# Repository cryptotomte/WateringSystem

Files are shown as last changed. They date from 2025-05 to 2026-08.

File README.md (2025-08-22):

# WateringSystem v2.3 (Hardware-Managed LDO Architecture)






## Overview
Cost-effective automated plant watering system with **2-domain optical isolation** for practical greenhouse automation. Features ESP32-based control, RS485 Modbus soil sensors, and simplified safety design optimized for enclosed environments.

**🔥 Latest Update v2.3**: Upgraded to TXS0108E bidirectional level shifter for faster RS485 communication - 1800x faster signal propagation while maintaining cost-effectiveness and reliability.

## Table of Contents
- [Features](#features)
- [Hardware Requirements](#hardware-requirements)
- [Software Dependencies](#software-dependencies)
- [Installation](#installation)
- [Usage](#usage)
- [Documentation](#documentation)
- [Testing](#testing)
- [Safety](#safety)
- [Contributing](#contributing)
- [License](#license)

## 🌟 Key Features

### Practical Safety & Isolation
- **Fast Level Shifting**: TXS0108E provides rapid voltage translation (110 Mbps)
- **2-Domain Architecture**: ESP32 (3.3V) → FIELD Domain (5V, level shifted)
- **Cost Effective**: Ultra-low cost design with high performance
- **Greenhouse Optimized**: Practical design for enclosed 12V environments

### Professional Monitoring
- **Multi-Parameter Soil Analysis**: NPK, pH, EC, moisture, temperature via RS485 Modbus
- **Environmental Sensing**: BME280 for ambient temperature, humidity, pressure
- **Real-time Monitoring**: Web interface with live sensor data
- **Remote Web Interface**: Responsive monitoring and configuration portal

### Smart Power Management
- **Hardware-Only Control**: LDO voltage converters provide always-on power management
- **Extended Runtime**: >48h operation on 20Ah LiFePO4 battery
- **Solar Ready**: MC4 connectors for future solar panel integration
- **Battery Monitoring**: Real-time voltage and capacity tracking
- **Simplified Design**: No software power control eliminates failure points
- **Instant Operation**: Always-on design eliminates startup delays

## 🔧 Hardware Architecture

### Hardware-Managed LDO System
```
12V LiFePO4 BATTERY ──┬── AMS1117-3.3 LDO ──► ESP32 Control Domain (Always-On)
                      │                      │ TXS0108E Level Shifter (3.3V↔5V)
                      │                      └── FIELD Domain (RS485 + Sensors)
                      │
                      └── AMS1117-5.0 LDO ──► Field Power Supply (Always-On)
                               │
                               └── Common Ground (GND_COMMON)
```

### Core Components
| Component | Model | Function | Domain |
|---|---|---|---|
| Microcontroller | ESP32-WROOM-32E | Main processor + WiFi | 3.3V Always-On |
| RS485 Interface | **SP3485EN** | Modbus communication | 5V Always-On |
| Level Shifter | **TXS0108E** | 3.3V↔5V voltage translation | Signal Path |
| Power Regulation | **AMS1117** | LDO voltage regulators | Hardware Control |
| Environmental | BME280 | Temperature/humidity | 3.3V Control |
| Soil Sensor | RS485 Modbus | NPK/pH/EC/moisture | 5V Field |

### ⚡ Hardware-Managed Safety Features
**LDO-based design provides reliable, always-on operation:**
- **Fast Level Shifting**: TXS0108E (110 Mbps capability with 10ns propagation)
- **Hardware Control**: LDO regulators eliminate software power management
- **Common Ground**: Simplified design prevents ground loop issues
- **Always-On**: Eliminates startup delays and power sequencing complexity
- **Maintenance Free**: No complex power domain monitoring required

## Software Dependencies
- **Framework**: Arduino framework for ESP32
- **Build System**: PlatformIO
- **Libraries**:
  - Wire (for I2C communication)
  - Adafruit BME280 (for environmental sensor)
  - ModbusMaster (for RS485 soil sensor)
  - ESPAsyncWebServer (for web interface)
  - AsyncElegantOTA (for OTA updates)
  - LittleFS (for file storage)
  - ArduinoJson (for data processing)

## Installation
1. Clone the repository:
```bash
git clone https://github.com/cryptotomte/WateringSystem.git
cd WateringSystem
```

2. Install PlatformIO (if not already installed):
```bash
pip install platformio
```

### Windows PowerShell Commands
On Windows systems, PlatformIO may not be in PATH. Use these commands:

```powershell
# Build project
& "C:\Users\crypt\.platformio\penv\Scripts\pio.exe" run --environment wateringsystem

# Upload to device  
& "C:\Users\crypt\.platformio\penv\Scripts\pio.exe" run --target upload --environment wateringsystem
```

3. Build and upload the firmware:
```bash
platformio run --target upload
```

4. Upload the file system (for web interface):
```bash
platformio run --target uploadfs
```

## Usage
1. **Initial Setup**
   - Power on the device
   - Connect to the WiFi network "WateringSystem-XXXX"
   - Navigate to 192.168.4.1 in your web browser
   - Follow the setup wizard to configure your home WiFi network

2. **Web Interface**
   - Access the web interface by navigating to the IP address of the device
   - Monitor current environmental and soil conditions
   - Configure watering schedules and thresholds
   - View historical data and system logs

3. **OTA Updates**
   - Access the update page at http://[device-ip]/update
   - Upload new firmware files through the web interface

## Documentation
Detailed documentation is available in the `docs` directory:
- [System Requirements Specification](docs/requirements.md)
- [Architecture Documentation](docs/architecture.md)
- [Hardware Documentation](docs/hardware.md)
- [User Guide](docs/user-guide.md)
- [Testing Documentation](docs/testing.md)
- [Safety Documentation](docs/safety.md)
- [Release Notes](docs/release-notes.md)

## Testing
The system includes unit tests and integration tests that can be executed using PlatformIO:

```bash
# Run all tests
platformio test

# Run specific test
platformio test -e test_sensors
```

For complete testing documentation, see [Testing Documentation](docs/testing.md).

## Safety
The WateringSystem interfaces with both water and electricity. Important safety considerations:
- All electrical components must be properly isolated from water
- Use waterproof enclosure for outdoor installations
- Include proper grounding for lightning protection in outdoor installations
- Power supply must be isolated and conform to safety standards

For complete safety information, see [Safety Documentation](docs/safety.md).

## Contributing
Contributions to the WateringSystem project are welcome! Please read [CONTRIBUTING.md](CONTRIBUTING.md) for details on our code of conduct and the process for submitting pull requests.

## License
This project is licensed under the GNU Affero General Public License v3.0 or later (AGPL-3.0-or-later) - see the [LICENSE](LICENSE) file for details.

**Key License Points:**
- ✅ Commercial use allowed
- ✅ Private use allowed  
- ✅ Modification allowed
- ⚠️ **Must share source code** when distributing binaries
- ⚠️ **Must share source code** when running as network service (SaaS)
- ⚠️ **Must preserve copyright** and license notices
- ⚠️ All modifications must use the same license

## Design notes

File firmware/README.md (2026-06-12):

# WateringSystem firmware (ESP-IDF)

ESP-IDF based firmware for the WateringSystem greenhouse controller
(ESP32-WROOM-32E, 4MB flash). This is the successor to the frozen
Arduino/PlatformIO firmware in the repository root.

- **ESP-IDF version:** v6.0.1 (pinned — in `Dockerfile` and CI)
- **Chip target:** `esp32`
- **Language:** C++ (IDF defaults, ~C++23 feature level)

## Building without a local toolchain (recommended)

No local ESP-IDF installation is needed. Always build with an **explicit
board selection**. From this `firmware/` directory:

```bash
# Rev 1 — ESP32 devkit + breakout (TXS0108E + SP3485)
docker run --rm -v "$PWD":/project -w /project espressif/idf:v6.0.1 \
  idf.py -DSDKCONFIG_DEFAULTS="sdkconfig.defaults;sdkconfig.board.rev1_devkit" build

# Rev 2 — custom PCB (THVD1426 auto-direction, INA226, CP2102N)
docker run --rm -v "$PWD":/project -w /project espressif/idf:v6.0.1 \
  idf.py -DSDKCONFIG_DEFAULTS="sdkconfig.defaults;sdkconfig.board.rev2" build
```

> **Warning:** omitting `SDKCONFIG_DEFAULTS` silently builds **rev1_devkit**
> (the Kconfig default), and the binaries are **identically named** for both
> boards. The two boards differ in safety-relevant ways (e.g. inverted level
> sensor polarity on rev2). Before flashing rev2 hardware, always verify the
> `Board:` line in the boot log matches the hardware.
>
> **Warning:** when switching boards, delete the generated `sdkconfig` (or
> run `idf.py fullclean`) first — overlays are only applied when `sdkconfig`
> is regenerated; otherwise the previous board's config is silently reused.

The first run pulls the image (~2 GB) and resolves managed components into
`managed_components/` (gitignored; `dependencies.lock` is tracked).

Pin mappings and board feature flags live in
`components/board/include/board/board.h` behind
`CONFIG_BOARD_REV1_DEVKIT` / `CONFIG_BOARD_REV2`.

## Host tests (no hardware needed)

The pump enforcement logic (timed runs, hard 300 s max-runtime cap, runtime
statistics) is pure C++ and is unit-tested natively on the ESP-IDF **linux
preview target** with the IDF-bundled Unity framework. From the repository:

```bash
cd firmware/test_apps/host
docker run --rm -v "$PWD":/project -w /project espressif/idf:v6.0.1 bash -c \
  "idf.py --preview set-target linux && idf.py build && ./build/pump_host_tests.elf"
echo $?   # 0 = all tests pass; >0 = number of failures
```

> **Note (macOS/OneDrive):** copy the tree to `/tmp` before mounting in
> Docker — the OneDrive path cannot be docker-mounted.

Coverage: max-runtime enforcement, duration self-stop, rejected starts
(0 s, > 300 s, already running), stop-when-stopped no-op, paired output
transitions and runtime statistics — all on a deterministic fake clock
(no sleeps). CI runs the same suite in the `host-test` job; the executable's
exit code equals the Unity failure count.

## Serial diagnostic console

The firmware starts an `esp_console` REPL on UART0 (same port as the logs,
115200 baud, prompt `ws>`) for bench-rig testing:

```
pump <plant|reservoir> start <seconds>   # timed run; 1..300
pump <plant|reservoir> stop
pump <plant|reservoir> status
pump status                              # both pumps
```

`help` lists all commands. Exact response formats are specified in
`specs/002-pump-gpio-board/contracts/serial-diagnostic.md`; the HIL
acceptance checklist is `specs/002-pump-gpio-board/checklists/hil.md`.

## Flash and monitor (initial bring-up only)

Routine updates will be delivered via OTA (phase 5). For initial bring-up,
flash over USB serial:

```bash
# With a local ESP-IDF installation:
idf.py -p /dev/ttyUSB0 flash monitor      # Linux
idf.py -p /dev/cu.usbserial-0001 flash monitor  # macOS

# Exit monitor with Ctrl-]
```

Docker on macOS cannot pass through USB serial devices; for bring-up either
use a Linux host (`docker run --device /dev/ttyUSB0 ...`) or flash the
CI-built binaries with esptool:

```bash
esptool.py --chip esp32 -p <PORT> write_flash \
  0x1000  build/bootloader/bootloader.bin \
  0x8000  build/partition_table/partition-table.bin \
  0x10000 build/wateringsystem.bin
```

## Partition layout (4MB)

| Name | Type | SubType  | Offset | Size | Purpose |
|---|---|---|---|---|---|
| nvs | data | nvs | 0x9000 | 0x4000 | Configuration storage |
| otadata  | data | ota | 0xd000 | 0x2000 | OTA slot selection |
| phy_init | data | phy | 0xf000 | 0x1000 | RF calibration data |
| ota_0 | app  | ota_0 | 0x10000  | 0x180000 | Application slot A |
| ota_1 | app  | ota_1 | 0x190000 | 0x180000 | Application slot B |
| storage  | data | littlefs | 0x310000 | 0xF0000  | Web assets, data logging |

A/B app slots with `CONFIG_BOOTLOADER_APP_ROLLBACK_ENABLE=y` provide
automatic rollback after a failed OTA boot (OTA itself arrives in phase 5).

## CI

`.github/workflows/firmware-build.yml` builds both board variants with
ESP-IDF v6.0.1 and uploads the binaries as artifacts. The push trigger is
**main-only**; feature branches build via PR or manual `workflow_dispatch`.

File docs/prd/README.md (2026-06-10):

# PRD breakdown — ESP-IDF migration

This directory breaks the master PRD ([`docs/PRD-esp-idf-migration.md`](../PRD-esp-idf-migration.md))
into PR-sized work packages for phases 1–6 of the Arduino → ESP-IDF firmware migration.

## How these files are used (spec-kit workflow)

Each `PR-NN-short-name.md` is a mini-PRD that seeds exactly one spec-kit feature run:

```
docs/prd/PR-NN-short-name.md
        │  speckit.specify / clarify / plan / tasks
        ▼
branch NNN-short-name  +  specs/NNN-short-name/ (spec.md, plan.md, tasks.md, checklists)
        │  implementation (subagents), checkpoints 1–3
        ▼
one reviewable PR to main (merge commit, never squash)
```

Rules (from the master PRD's working-method section):

- One PR-NN file → one feature branch → one PR. Each PR must merge with CI green.
- Implementer always delivers a test checklist: **CI**-tagged acceptance criteria are
  verified by GitHub Actions; **HIL**-tagged criteria become a checklist Paul runs on
  the bench rig (rev1 devkit + RS485 + soil sensor) at checkpoint 3.
- All commits, code, docs and issues in English (public repo).
- Order below keeps CI green at every merge point: no PR depends on unmerged work.

## Sync gates (parallel hardware track)

| Gate | Event | Gates |
|---|---|---|
| **SYNC 1** | rev2 pin map frozen (KiCad schematic done) | Final `BOARD_REV2` pin table in the board component (PR-02 ships rev1 table + provisional rev2 table; rev2 table is finalized at SYNC 1, at the latest before PR-14) |
| **SYNC 2** | rev2 boards delivered (JLCPCB) | All of phase 6 (PR-14) |

Phases 1–5 are developed and verified entirely on the rev1 devkit rig; the greenhouse
unit is never touched.

## Dependency graph

```
PR-01 phase0-foundation (done — this PR)
  │
  ├─► PR-02 pump-gpio-board ──◄ SYNC 1 (final rev2 pin table)
  │     ├─► PR-03 bme280-i2c
  │     ├─► PR-04 modbus-soil-sensor
  │     └─► PR-05 level-sensors-ina226
  │
  ├─► PR-06 nvs-littlefs-storage
  │     └─► PR-07 wifi-provisioning
  │           └─► PR-08 sntp-watchdog-logging
  │
  │   PR-06 + PR-07 ──► PR-09 http-server-api-v1 ──► PR-10 frontend-littlefs-assets
  │                          (live data: PR-03/04/05)
  │
  │   PR-02..05 + PR-06 + PR-08 ──► PR-11 watering-controller-host-tests
  │
  │   PR-09..11 ──► PR-12 parity-validation (HIL)
  │
  │   PR-06 + PR-09 ──► PR-13 ota-release
  │
  └────────────────► PR-14 rev2-bringup ◄── SYNC 2 (boards delivered)
                          (after PR-12 + PR-13)
```

## Work packages

| PR | Title | Phase | Depends on | Sync gates | Size | Status |
|---|---|---|---|---|---|---|
| PR-01 | [phase0-foundation](PR-01-phase0-foundation.md) | 0 | — | — | L | **done** (this PR) |
| PR-02 | [pump-gpio-board](PR-02-pump-gpio-board.md) | 1 | PR-01 | SYNC 1 (final rev2 table) | M | pending |
| PR-03 | [bme280-i2c](PR-03-bme280-i2c.md) | 1 | PR-02 | — | M | pending |
| PR-04 | [modbus-soil-sensor](PR-04-modbus-soil-sensor.md) | 1 | PR-02 | — | M | pending |
| PR-05 | [level-sensors-ina226](PR-05-level-sensors-ina226.md) | 1 | PR-02 | — | M | pending |
| PR-06 | [nvs-littlefs-storage](PR-06-nvs-littlefs-storage.md) | 2 | PR-01 | — | M | pending |
| PR-07 | [wifi-provisioning](PR-07-wifi-provisioning.md) | 2 | PR-06 | — | L | pending |
| PR-08 | [sntp-watchdog-logging](PR-08-sntp-watchdog-logging.md) | 2 | PR-06, PR-07 | — | M | pending |
| PR-09 | [http-server-api-v1](PR-09-http-server-api-v1.md) | 3 | PR-06, PR-07 (live data: PR-03/04/05) | — | L | pending |
| PR-10 | [frontend-littlefs-assets](PR-10-frontend-littlefs-assets.md) | 3 | PR-09 | — | M | pending |
| PR-11 | [watering-controller-host-tests](PR-11-watering-controller-host-tests.md) | 4 | PR-02..05, PR-06, PR-08 | — | L | pending |
| PR-12 | [parity-validation](PR-12-parity-validation.md) | 4 | PR-09, PR-10, PR-11 | — | M | pending |
| PR-13 | [ota-release](PR-13-ota-release.md) | 5 | PR-06, PR-09 | repo-publication decision | L | pending |
| PR-14 | [rev2-bringup](PR-14-rev2-bringup.md) | 6 | PR-05, PR-12, PR-13 | **SYNC 2** | L | pending |

## Notes on the split

- The breakdown follows the master PRD's phase definitions (Fasdefinitioner table)
  one-to-one; each phase's completion criterion is covered by the last PR of that phase.
- PR-02 carries the board component (pin maps, Kconfig feature flags) because the pump
  driver is the smallest driver and every other phase-1 PR consumes the board component.
- INA226 rides with the level sensors in PR-05 (both are small, rev2-relevant drivers;
  INA226 is driver + raw measurements only — protection features are an explicit
  non-goal, see master PRD "Ingår EJ").
- PR-12 (parity validation) is a thin PR by design: its deliverable is the ticked-off
  `docs/parity-checklist.md` plus gap fixes found on the rig — kept separate from PR-11
  so the host-tested controller port merges without waiting for rig time.

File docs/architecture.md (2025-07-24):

# WateringSystem Architecture

## Overview

This document describes the architectural design of the WateringSystem project. The architecture follows a modular, layered approach with clear separation of concerns and interface-based design principles.

## System Architecture

The WateringSystem follows a layered architecture pattern to ensure modularity, testability, and maintainability. The system is divided into the following layers:

```
┌─────────────────────────────────────────────┐
│               User Interface                │
│         (Web Server, HTML/CSS/JS)           │
└───────────────────────┬─────────────────────┘
                        │
┌───────────────────────▼─────────────────────┐
│             Application Logic                │
│      (Watering Rules, Scheduling, etc.)     │
└───────────────────────┬─────────────────────┘
                        │
┌───────────────────────▼─────────────────────┐
│           Service Layer                      │
│  (Sensor Data Processing, Data Storage)      │
└───────────────────────┬─────────────────────┘
                        │
┌───────────────────────▼─────────────────────┐
│        Hardware Abstraction Layer            │
│    (Sensor & Actuator Interface Classes)     │
└───────────────────────┬─────────────────────┘
                        │
┌───────────────────────▼─────────────────────┐
│             Hardware Drivers                 │
│     (BME280, RS485, Soil Sensor, Pump)      │
└─────────────────────────────────────────────┘
```

### Layers Description

1. **User Interface Layer**
   - Provides web-based interface for monitoring and control
   - Implements a lightweight web server
   - Serves HTML, CSS, and JavaScript content from LittleFS
   - Handles user authentication and authorization

2. **Application Logic Layer**
   - Implements watering rules and decision logic
   - Manages scheduling and timing of watering events
   - Handles alerts and notifications for out-of-range conditions
   - Processes user configuration changes

3. **Service Layer**
   - Processes raw sensor data into meaningful values
   - Manages data persistence (configuration, logs, history)
   - Implements Modbus RTU protocol for soil sensor communication
   - Provides data access services to upper layers

4. **Hardware Abstraction Layer**
   - Defines interfaces for all hardware components
   - Provides concrete implementations for each hardware device
   - Abstracts hardware details from upper layers
   - Enables mock implementations for testing

5. **Hardware Drivers Layer**
   - Implements low-level communication with hardware
   - Handles I2C, RS485, and GPIO communications
   - Manages power control and timing requirements
   - Reports hardware errors to upper layers

## Component Diagram

```
┌─────────────────────────────────────────────────────────────────┐
│                         WateringSystem                          │
└───────────────────────────────┬─────────────────────────────────┘
                                │
        ┌─────────────────────────────────────────────┐
        │                                             │
┌───────▼────────┐    ┌────────────────┐    ┌─────────▼─────────┐
│    WebServer   │    │ ConfigManager  │    │   SensorManager   │
└───────┬────────┘    └────────┬───────┘    └─────────┬─────────┘
        │                      │                      │
        │             ┌────────▼───────┐     ┌────────▼────────┐
        │             │ DataRepository │     │  SensorFactory  │
        │             └────────────────┘     └────────┬────────┘
        │                                             │
┌───────▼────────┐                           ┌────────▼────────┐
│   HTTPHandler  │                           │   ISensor       │◄────┐
└────────────────┘                           └────────┬────────┘     │
                                                      │              │
                          ┌─────────────────┬─────────┼──────────┐   │
                          │                 │         │          │   │
                 ┌────────▼───────┐ ┌───────▼────┐ ┌─▼────────┐ │   │
                 │ BME280Sensor   │ │ SoilSensor │ │ MockSensor│ │   │
                 └────────────────┘ └───────┬────┘ └───────────┘ │   │
                                            │                    │   │
                                    ┌───────▼────────┐           │   │
                                    │ ModbusClient   │           │   │
                                    └────────────────┘           │   │
                                                                 │   │
┌────────────────┐                                   ┌───────────▼─┐ │
│ WateringRules  │◄──────────────────────────────────┤ SensorReading│ │
└───────┬────────┘                                   └───────────┬─┘ │
        │                                                        │   │
┌───────▼────────┐                                               │   │
│ PumpController │◄──────────────────────────────────────────────┘   │
└───────┬────────┘                                                    │
        │                                                             │
┌───────▼────────┐     ┌────────────────┐                            │
│   IActuator    │◄────┤  MockActuator  │────────────────────────────┘
└───────┬────────┘     └────────────────┘
        │
┌───────▼────────┐
│    WaterPump   │
└────────────────┘
```

## Key Interfaces

The architecture is built around a set of key interfaces that enable modularity and testability:

### Sensor Interfaces

```cpp
/**
 * Base interface for all sensors
 */
class ISensor {
public:
    virtual ~ISensor() = default;
    
    /**
     * Initialize the sensor
     * @return true if initialization successful, false otherwise
     */
    virtual bool initialize() = 0;
    
    /**
     * Read sensor data
     * @return true if reading successful, false otherwise
     */
    virtual bool read() = 0;
    
    /**
     * Check if sensor is available and working
     * @return true if sensor is available, false otherwise
     */
    virtual bool isAvailable() = 0;
    
    /**
     * Get last error code
     * @return error code, 0 if no error
     */
    virtual int getLastError() = 0;
};

/**
 * Interface for environmental sensors
 */
class IEnvironmentalSensor : public ISensor {
public:
    /**
     * Get temperature in Celsius
     * @return temperature value
     */
    virtual float getTemperature() = 0;
    
    /**
     * Get relative humidity in percent
     * @return humidity value
     */
    virtual float getHumidity() = 0;
};

/**
 * Interface for soil sensors
 */
class ISoilSensor : public ISensor {
public:
    /**
     * Get soil moisture in percent
     * @return moisture value
     */
    virtual float getMoisture() = 0;
    
    /**
     * Get soil temperature in Celsius
     * @return temperature value
     */
    virtual float getTemperature() = 0;
    
    /**
     * Get soil pH level
     * @return pH value
     */
    virtual float getPH() = 0;
    
    /**
     * Get electrical conductivity in µS/cm
     * @return EC value
     */
    virtual float getEC() = 0;
    
    /**
     * Get nitrogen level
     * @return nitrogen value
     */
    virtual float getNitrogen() = 0;
    
    /**
     * Get phosphorus level
     * @return phosphorus value
     */
    virtual float getPhosphorus() = 0;
    
    /**
     * Get potassium level
     * @return potassium value
     */
    virtual float getPotassium() = 0;
};
```

### Actuator Interfaces

```cpp
/**
 * Base interface for all actuators
 */
class IActuator {
public:
    virtual ~IActuator() = default;
    
    /**
     * Initialize the actuator
     * @return true if initialization successful, false otherwise
     */
    virtual bool initialize() = 0;
    
    /**
     * Check if actuator is available and working
     * @return true if actuator is available, false otherwise
     */
    virtual bool isAvailable() = 0;
    
    /**
     * Get last error code
     * @return error code, 0 if no error
     */
    virtual int getLastError() = 0;
};

/**
 * Interface for water pump control
 */
class IWaterPump : public IActuator {
public:
    /**
     * Start the pump
     * @return true if operation successful, false otherwise
     */
    virtual bool start() = 0;
    
    /**
     * Stop the pump
     * @return true if operation successful, false otherwise
     */
    virtual bool stop() = 0;
    
    /**
     * Run the pump for a specific duration
     * @param seconds Duration to run in seconds
     * @return true if operation successful, false otherwise
     */
    virtual bool runFor(unsigned int seconds) = 0;
    
    /**
     * Check if the pump is currently running
     * @return true if running, false otherwise
     */
    virtual bool isRunning() = 0;
};
```

### Communication Interfaces

```cpp
/**
 * Interface for Modbus communication
 * 
 * Implementation Note (July 2025): SP3485ModbusClient provides production-ready
 * RS485 communication using TXS0108E level shifter with verified 50µs timing delays.
 * Supports full Modbus RTU protocol with error handling and automatic retry logic.
 */
class IModbusClient {
public:
    virtual ~IModbusClient() = default;
    
    /**
     * Initialize the Modbus client
     * @return true if initialization successful, false otherwise
     */
    virtual bool initialize() = 0;
    
    /**
     * Read holding registers from a Modbus device
     * @param deviceAddress Modbus device address
     * @param startRegister First register to read
     * @param count Number of registers to read
     * @param buffer Buffer to store read values
     * @return true if operation successful, false otherwise
     */
    virtual bool readHoldingRegisters(uint8_t deviceAddress, uint16_t startRegister, 
                                      uint16_t count, uint16_t* buffer) = 0;
    
    /**
     * Write single register to a Modbus device
     * @param deviceAddress Modbus device address
     * @param registerAddress Register address to write
     * @param value Value to write
     * @return true if operation successful, false otherwise
     */
    virtual bool writeSingleRegister(uint8_t deviceAddress, uint16_t registerAddress, 
                                    uint16_t value) = 0;
    
    /**
     * Get last error code
     * @return error code, 0 if no error
     */
    virtual int getLastError() = 0;
};
```

### Storage Interfaces

```cpp
/**
 * Interface for data storage
 */
class IDataStorage {
public:
    virtual ~IDataStorage() = default;
    
    /**
     * Initialize the storage
     * @return true if initialization successful, false otherwise
     */
    virtual bool initialize() = 0;
    
    /**
     * Store configuration data
     * @param key Configuration key
     * @param data Data to store
     * @return true if operation successful, false otherwise
     */
    virtual bool storeConfig(const String& key, const String& data) = 0;
    
    /**
     * Retrieve configuration data
     * @param key Configuration key
     * @param defaultValue Default value if key not found
     * @return Retrieved data or default value
     */
    virtual String getConfig(const String& key, const String& defaultValue = "") = 0;
    
    /**
     * Store sensor reading
     * @param sensorId ID of the sensor
     * @param readingType Type of reading (temperature, humidity, etc.)
     * @param value Reading value
     * @param timestamp Time of reading
     * @return true if operation successful, false otherwise
     */
    virtual bool storeSensorReading(const String& sensorId, const String& readingType, 
                                  float value, time_t timestamp) = 0;
    
    /**
     * Get sensor readings for a specific period
     * @param sensorId ID of the sensor
     * @param readingType Type of reading
     * @param startTime Start time of the period
     * @param endTime End time of the period
     * @return JSON string with readings
     */
    virtual String getSensorReadings(const String& sensorId, const String& readingType, 
                                   time_t startTime, time_t endTime) = 0;
};
```

## Data Flow

1. **Sensor Data Collection**
   - Sensors are read at configured intervals
   - Raw data is processed and converted to appropriate units
   - Processed data is stored in temporary storage
   - Readings are checked against configured thresholds

2. **Decision Making**
   - Soil moisture and other parameters are evaluated
   - If watering criteria are met, watering process is triggered
   - Historical data is considered for decision making
   - Scheduling rules are applied

3. **Actuation**
   - Water pump is activated for a calculated duration
   - Pump activity is monitored and logged
   - Safety checks are performed during operation

4. **User Interaction**
   - Web interface displays current status and historical data
   - User configures system parameters and schedules
   - System responds to manual commands
   - Alerts are displayed for out-of-range conditions

## Testing Approach

The architecture supports comprehensive testing at multiple levels:

1. **Unit Testing**
   - Each class is tested in isolation
   - Mock implementations of interfaces are used
   - Focus on individual component behavior

2. **Integration Testing**
   - Tests interaction between components
   - Verifies proper communication between layers
   - Focuses on interface compliance

3. **System Testing**
   - Tests the complete system behavior
   - Verifies end-to-end functionality
   - Simulates real-world scenarios

## Deployment

The system is deployed as firmware on the ESP32 microcontroller:

1. **Build Process**
   - PlatformIO builds the firmware
   - Web assets are processed and included in the binary
   - Configuration is embedded in the firmware

2. **Installation**
   - Firmware is flashed to the ESP32
   - Initial configuration is performed
   - System performs self-test and calibration

3. **Updates**
   - OTA (Over The Air) updates are supported
   - Configuration is preserved during updates
   - Version control ensures compatibility

## Future Extensions

The architecture is designed to support future extensions:

1. **Additional Sensors**
   - New sensor types can be added through interface implementation
   - Minimal impact on existing code

2. **Advanced Control Algorithms**
   - More sophisticated watering algorithms can be implemented
   - Machine learning integration for predictive watering

3. **External Integrations**
   - MQTT support for IoT integration
   - REST API for external system integration

4. **Mobile Application**
   - Companion mobile app could be developed
   - Would communicate with system via web API

## Hardware Architecture - LDO-Managed System

The WateringSystem implements a hardware-managed power architecture optimized for greenhouse automation applications. The system uses LDO voltage regulators with common ground and optical signal isolation, providing reliable operation without software power control complexity.

### Hardware-Managed Power Overview

The system uses an always-on LDO architecture with optical signal isolation:

```
┌─────────────────────────────────────────────────────────────────┐
│                 ESP32 Domain (3.3V LDO)                         │
│  ┌─────────────┐  ┌─────────────┐  ┌─────────────┐             │
│  │    ESP32    │  │   BME280    │  │  Status     │             │
│  │  DevKit v1  │  │   Sensor    │  │  LEDs       │             │
│  └─────────────┘  └─────────────┘  └─────────────┘             │
│                         │                                       │
│                         │ I2C (Direct connection)               │
│                         │                                       │
│  Reference: GND_COMMON                                          │
└───────────────────┬─────────────────────────────────────────────┘                    │ Level Shifting
                    │ (TXS0108E)
                    │ 3.3V ↔ 5V
┌───────────────────▼─────────────────────────────────────────────┐
│                 FIELD Domain (5V LDO Always-On)                 │
│  ┌─────────────────────────────────────────────────────────┐   │
│  │                SP3485EN IC                              │   │
│  │           RS485 Transceiver                             │   │
│  │          (Always powered)                               │   │
│  └─────────────────────────────────────────────────────────┘   │
│                                                                 │
│  ┌─────────────┐  ┌─────────────┐  ┌─────────────┐             │
│  │    Soil     │  │   Water     │  │  Reservoir  │             │
│  │   Sensors   │  │   Pumps     │  │   Sensors   │             │
│  │  (RS485)    │  │  (Relays)   │  │  (Digital)  │             │
│  └─────────────┘  └─────────────┘  └─────────────┘             │
│                                                                 │
│  Reference: GND_COMMON (Shared ground)                         │
└─────────────────────────────────────────────────────────────────┘
```

### Hardware Management Strategy

#### LDO Power Management: Always-On Design
- **Type**: AMS1117 LDO voltage regulators
- **ESP32 Domain**: 3.3V always-on power supply
- **Field Domain**: 5V always-on power supply
- **Ground**: Common ground plane (GND_COMMON)
- **Control**: Hardware-only, no software power management

#### TXS0108E Level Shifter: Fast Voltage Translation
- **Type**: 8-bit bidirectional voltage translator
- **Data Rate**: Up to 110 Mbps capability
- **Purpose**: Signal isolation between domains (signals only, not power)
- **Signals Isolated**: TX, RX, DE/RE control
- **Cost**: ~60 SEK total (3 units × 20 SEK)

### Hardware Benefits

1. **Simplicity**: No software power control eliminates complexity and failure modes
2. **Reliability**: Always-on design eliminates startup delays and power sequencing issues
3. **Stability**: LDO regulators provide excellent voltage regulation and low noise
4. **Cost Effectiveness**: Eliminates need for power control GPIO pins and monitoring circuits
5. **Common Ground**: Shared ground plane simplifies PCB design and eliminates ground loops

### Power Supply Architecture

```
12V Battery ──┬── AMS1117-3.3 LDO ──► ESP32 Domain (3.3V Always-On)
              │   (GND_COMMON)        Control logic, WiFi, BME280
              │
              └── AMS1117-5.0 LDO ──► FIELD Domain (5V Always-On)
                  (GND_COMMON)        RS485, sensors, pumps
```

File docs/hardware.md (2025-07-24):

# Hardware Specifications - WateringSystem v2.3 (Hardware-Managed LDO Architecture)

## Overview

This document provides complete hardware specifications for the hardware-managed WateringSystem designed for cost-effective greenhouse automation. The system uses LDO voltage converters with common ground and optical signal isolation - optimized for always-on 12V applications with hardware-only power management.

## Main Components

### 1. Microcontroller - ESP32-WROOM-32E

| Specification | Value |
|---|---|
| CPU | Dual-core Xtensa LX6 microprocessor |
| Clock Speed | Up to 240 MHz |
| Flash Memory | 4 MB |
| RAM | 520 KB SRAM |
| Wireless | Wi-Fi 802.11 b/g/n (2.4 GHz) + Bluetooth 4.2 |
| GPIO Pins | 34 programmable GPIO pins |
| ADC | 12-bit SAR ADC, up to 18 channels |
| Power Supply | 3.3V |
| Operating Temperature | -40°C to +85°C |

### 2. Environmental Sensor - BME280

| Specification | Value |
|---|---|
| Interface | I2C (Address: 0x76 or 0x77) |
| Temperature Range | -40°C to +85°C |
| Temperature Accuracy | ±0.5°C |
| Humidity Range | 0% to 100% RH |
| Humidity Accuracy | ±3% RH |
| Pressure Range | 300 to 1100 hPa |
| Pressure Accuracy | ±1 hPa |
| Supply Voltage | 1.71V to 3.6V |
| Current Consumption | 3.6 μA at 1 Hz |

### 3. Soil Sensor - RS485 Modbus Soil Sensor

| Specification | Value |
|---|---|
| Interface | RS485 Modbus RTU |
| Baud Rate | 9600 bps (default) |
| Data Format | 8N1 (8 data bits, no parity, 1 stop bit) |
| Device Address | Configurable (default: 0x01) |
| Moisture Range | 0% to 100% |
| Temperature Range | -40°C to +80°C |
| pH Range | 3 to 9 pH |
| EC Range | 0 to 20000 μS/cm |
| NPK Range | Nitrogen: 0-1999 mg/kg, Phosphorus: 0-1999 mg/kg, Potassium: 0-1999 mg/kg |
| Supply Voltage | 5V DC (LDO-managed always-on) |
| Current Consumption | < 50 mA (typical) |
| Cable Length | Up to 200 meters (adequate for greenhouse) |

**Modbus Register Map**

| Register | Description | Unit | Format |
|---|---|---|---|
| 0x0000 | Soil Moisture | % | Unsigned 16-bit |
| 0x0001 | Soil Temperature | 0.1°C | Signed 16-bit |
| 0x0002 | Soil pH | 0.1 pH | Unsigned 16-bit |
| 0x0003 | Soil EC | μS/cm | Unsigned 16-bit |
| 0x0004 | Nitrogen | mg/kg | Unsigned 16-bit |
| 0x0005 | Phosphorus | mg/kg | Unsigned 16-bit |
| 0x0006 | Potassium | mg/kg | Unsigned 16-bit |
| 0x0007 | Soil Humidity | % | Unsigned 16-bit |

### 4. RS485 Interface - MIKROE-4156 with Optical Isolation

**MikroElektronika RS485 5 Click (MIKROE-4156)**

| Specification | Value |
|---|---|
| Interface | UART to RS485 |
| Transceiver IC | ADM3485ARZ (Analog Devices) |
| Signal Rate | Up to 12 Mbps |
| Operating Voltage | 5V (LDO-managed) |
| ESD Protection | ±15kV on bus pins |
| Bus Load | Supports up to 32 transceivers |
| Interface | mikroBUS™ connector |
| Dimensions | 25.4 x 28.58 mm |

**TXS0108E Level Shifter (Voltage Translation)**

| Specification | Value |
|---|---|
| Type | 8-bit bidirectional voltage translator |
| Input Voltage (A-side) | 1.2V to 3.6V (ESP32: 3.3V) |
| Input Voltage (B-side) | 1.65V to 5.5V (RS485: 5.0V) |
| Data Rate | Up to 110 Mbps |
| Propagation Delay | 10ns typical |
| Package | 20-pin TSSOP |
| Operating Temperature | -40°C to +85°C |
| Channels Used | 3 (TX, RX, DE/RE) |
| **Verified Timing** | **50µs DE/RE switching delays (tested July 2025)** |
| **Communication Rate** | **9600 baud Modbus RTU verified functional** |

### 5. Water Pumps - 12V DC

| Specification | Value |
|---|---|
| Operating Voltage | 12V DC |
| Current | 0.5A - 1.5A (depending on pressure) |
| Flow Rate | 1-3 liters per minute |
| Maximum Head | 2-3 meters |
| Power Consumption | 6-18W |
| Duty Cycle | 30 minutes max continuous operation |
| Quantity | 2 pieces (plant pump + reservoir pump) |

### 6. Power Supply Components

**LiFePO4 Battery**

| Specification | Value |
|---|---|
| Voltage | 12V nominal |
| Capacity | 20Ah (240Wh) |
| Type | LiFePO4 (safe chemistry) |
| Operating Temperature | 0°C to 45°C |
| Cycle Life | >2000 cycles |

**LDO Voltage Converters (Always-On Hardware Management)**

| Component | Input | Output | Current | Efficiency | Type |
|---|---|---|---|---|---|
| AMS1117-3.3 (ESP32 domain) | 12V | 3.3V | 1A | >85% | LDO |
| AMS1117-5.0 (Field domain) | 12V | 5V | 1A | >85% | LDO |

**Key Features:**
- Hardware-only power management (no software control)
- Always-on operation with low dropout voltage
- Common ground design eliminates ground loop issues
- Thermal protection and current limiting
- Stable output voltage regulation

## Pin Assignments - Hardware-Managed LDO Architecture with TXS0108E

| GPIO | Connected To | Description |
| GPIO | Connected To | Description |
|------|--------------|-------------|
| GPIO 21 | I2C SDA | BME280 Data Line |
| GPIO 22 | I2C SCL | BME280 Clock Line |
| GPIO 17 | TX2 | RS485 TX (via TXS0108E A1) |
| GPIO 16 | RX2 | RS485 RX (via TXS0108E A2) |
| GPIO 25 | DE/RE | RS485 Direction Control (via TXS0108E A3) |
| GPIO 26 | Plant Pump Control | Main Water Pump MOSFET Gate |
| GPIO 27 | Reservoir Pump Control | Reservoir Filling Pump MOSFET Gate |
| GPIO 32 | Reservoir Low Level | Water Reservoir Low Level Sensor |
| GPIO 33 | Reservoir High Level | Water Reservoir High Level Sensor |
| GPIO 2 | Status LED | System Status Indicator |
| GPIO 5 | Button 1 | Manual Mode Button |
| GPIO 18 | Button 2 | Configuration Button |

**Pin Configuration Updates (July 2025):**
- **CRITICAL FIX:** GPIO 16/17 pin assignments corrected for proper RS485 communication
- Previous configuration had TX/RX pins swapped causing communication failures
- Now matches verified working test configuration: TX=GPIO17, RX=GPIO16
- TXS0108E timing delays optimized to 50µs for reliable level shifting
- All RS485 communication now fully functional with Modbus soil sensors

## Power Architecture - Hardware-Managed LDO System

### Power Domains

| Domain | Voltage | Ground | Control | Components |
|---|---|---|---|---|
| **ESP32** | 3.3V | GND_COMMON | LDO Always-On | ESP32, BME280, Control logic |
| **FIELD** | 5V | GND_COMMON | LDO Always-On | RS485 module, Soil sensor |

### Power Distribution

```
12V LiFePO4 Battery
├── LDO 3.3V → ESP32 Domain (control, WiFi, sensors)
└── LDO 5V   → Field Domain (RS485 + soil sensor)
     └── Common Ground (GND_COMMON) - No isolation required
```

### Hardware-Only Management Strategy

- **Always-On Design:** Both LDO converters provide continuous regulated power
- **No Software Control:** Power domains managed entirely by hardware
- **Common Ground:** Single ground plane simplifies design and eliminates ground loops
- **Level Shifting:** TXS0108E provides fast bidirectional voltage translation for RS485 signals
- **Safety Level:** Practical for enclosed 12V systems in ASA IP65 box

## Connection Diagram

```
                        ┌─────────────────┐
                        │                 │                        │      ESP32      │
                        │   (3.3V LDO)    │
                        └─┬───┬───┬───┬───┘
                          │   │   │   │
                          │   │   │   │
┌─────────────┐           │   │   │   │           ┌────────────┐
│             │◄──SDA─────┘   │   │   │           │ TXS0108E   │
│   BME280    │               │   │   │           │(3.3V↔5V)   │
│             │◄──SCL─────────┘   │   └───TX────►│ A1    B1 ──┼──►
└─────────────┘                   │               │ A2    B2 ──┼──◄─RX
                                  └───DE/RE─────►│ A3    B3 ──┼──►
                                                  │ OE←VCC     │
                                                  └──────┬─────┘
┌─────────────┐                                          │
│  Reservoir  │                                    ┌─────▼─────┐
│  Low Level  │◄──GPIO32───┐                       │           │
│   Sensor    │            │                       │  MIKROE   │
└─────────────┘            │                       │   4156    │
                           │                       │  (5V LDO  │
┌─────────────┐            │                       │Always-On) │
│  Reservoir  │            │                       └─────┬─────┘
│  High Level │◄──GPIO33───┤                             │
│   Sensor    │            │                        ┌────▼─────┐
└─────────────┘            │                        │          │
                           │                        │  RS485   │
┌─────────────┐            │                        │   Soil   │
│   12V DC    │            │                        │  Sensor  │
│   Battery   ├──12V───────┼───────────────┬────────┤ (5V pow) │
│  (LiFePO4)  │            │               │        └──────────┘
└──────┬──────┘            │               │
       │                   │               │
       │                   │               │
┌──────▼──────┐            │          ┌────▼────┐
│   3.3V      │            │          │         │
│Buck Convert ├──3.3V──────┼──────────┤  Plant  │
│   LM2596    │            │          │  Pump   │
└─────────────┘            │          │ Control │
                           │          │         │
┌──────▼──────┐            │          └────┬────┘
│    5V       │            │               │
│Buck Convert ├──5V────────┼──────────┌────▼────┐
│   LM2596    │            │          │         │
└─────────────┘            │          │Reservoir│
                           │          │  Pump   │
┌─────────────┐            │          │ Control │
│   User      │            │          │         │
│  Interface  │◄───GPIO5/18┤          └────┬────┘
│  (Buttons)  │            │               │
└─────────────┘            │               │
                           │          ┌────▼────┐
┌─────────────┐            │          │         │
│   Status    │◄───GPIO2───┘          │  Water  │
│    LED      │                       │  Pumps  │
│             │                       │ (12V)   │
└─────────────┘                       └─────────┘
```

## Bill of Materials (BOM) - Simplified v2.2

| Item | Description | Quantity | Unit Price (SEK) | Total (SEK) | Notes |
|---|---|---|---|---|---|
| 1 | ESP32-WROOM-32E Module | 1 | 120 | 120 | Main microcontroller |
| 2 | BME280 Sensor Module | 1 | 50 | 50 | Environmental sensing |
| 3 | RS485 Soil Sensor (NPK) | 1 | 600 | 600 | Soil parameters measurement |
| 4 | MIKROE-4156 RS485 5 Click | 1 | 200 | 200 | RS485 transceiver |
| 5 | TXS0108E Level Shifter | 1 | 8 | 8 | 3.3V↔5V voltage translation |
| 6 | 12V DC Water Pump | 2 | 150 | 300 | Plant + reservoir pumps |
| 7 | IRLZ44N N-Channel MOSFET | 2 | 10 | 20 | Pump control |
| 8 | 1N4007 Diode | 2 | 2 | 4 | Flyback protection |
| 9 | Water Level Sensor | 2 | 25 | 50 | Reservoir level detection |
| 10 | LiFePO4 12V 20Ah Battery | 1 | 800 | 800 | Main power source |
| 11 | AMS1117-3.3 LDO Regulator | 1 | 25 | 25 | 3.3V always-on power |
| 12 | AMS1117-5.0 LDO Regulator | 1 | 25 | 25 | 5V always-on power |
| 13 | Capacitors (various) | 15 | 3 | 45 | Power filtering |
| 14 | Resistors (various) | 20 | 1 | 20 | Current limiting, pull-up/down |
| 15 | Status LEDs | 3 | 5 | 15 | Status indication |
| 16 | Push Buttons | 2 | 10 | 20 | User interface |
| 17 | Terminal Blocks | 8 | 8 | 64 | Connections |
| 18 | PCB (2-layer) | 1 | 150 | 150 | Custom designed |
| 19 | ASA Enclosure IP65 | 1 | 200 | 200 | Weather protection |
| 20 | Water Tubing (silicone) | 3m | 20 | 60 | Food-grade |
| 21 | Shielded Twisted Pair | 5m | 15 | 75 | RS485 connection |
| 22 | Water Reservoir | 1 | 100 | 100 | Storage container |
| 23 | Misc (screws, wire, etc.) | 1 | 100 | 100 | Assembly materials |
| | | | **TOTAL** | **2998 SEK** | |

## Power Requirements

| Component | Voltage | Current (Peak) | Power (W) |
|---|---|---|---|
| ESP32 | 3.3V | 250mA | 0.8 |
| BME280 | 3.3V | 1mA | 0.003 |
| TXS0108E | 3.3V/5V | 2mA | 0.007 |
| RS485 Module | 5V | 100mA | 0.5 |
| Soil Sensor | 5V | 50mA | 0.25 |
| Water Pump (active) | 12V | 1.5A | 18 |
| **Total (pump off)** | | | **1.56W** |
| **Total (pump on)** | | | **19.56W** |

**Battery Life Calculation:**
- Normal operation: 240Wh ÷ 1.56W = ~154 hours (6.4 days)
- With 30min pumping/day: ~140 hours (5.8 days)

## Safety Features

### Optical Isolation
- **Fast level shifting** via TXS0108E (110 Mbps capability)
- **Voltage translation** between ESP32 (3.3V) and field domains (5V)
- **Bidirectional communication** with minimal propagation delay (10ns)

### Hardware-Managed Power
- **Always-on LDO design** provides continuous regulated power
- **No software power control** eliminates complexity and failure points
- **Common ground design** prevents ground loop issues

### Environmental Protection
- **IP65 enclosure** for outdoor installations
- **Operating temperature:** 0°C to 50°C
- **Storage temperature:** -10°C to 60°C

## Installation Notes

### Greenhouse Deployment
1. Mount in ASA IP65 enclosure
2. Position away from direct sunlight
3. Ensure adequate ventilation
4. Waterproof all external connections

### RS485 Bus Configuration
- Use twisted pair cable for A and B signals
- Maximum cable length: 200m for greenhouse applications
- No termination resistors needed for short runs (<50m)

### Power Optimization
- LDO regulators provide stable voltage regulation
- LiFePO4 battery safe for indoor/greenhouse use
- Always-on design eliminates startup delays
- Solar charging capability (MC4 connectors planned)

## Future Expansions

### Planned Additions
- Solar charging controller (10W panel)
- Additional soil sensors (up to 8 on RS485 bus)
- Weather station integration
- LoRa communication for remote monitoring

### Hardware Provisions
- Spare GPIO pins for expansion
- Extra power capacity for additional sensors
- Modular PCB design for easy modifications

This simplified 2-domain architecture provides cost-effective greenhouse automation while maintaining essential safety features through optical isolation. The design prioritizes practical implementation over complex isolation schemes.

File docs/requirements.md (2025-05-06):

# System Requirements Specification

## 1. Introduction
### 1.1 Purpose
This document outlines the requirements for the WateringSystem project, an automated plant watering system designed to maintain optimal soil moisture levels for indoor or garden plants. The purpose of this document is to define the functional and non-functional requirements of the system to guide development and testing.

### 1.2 Scope
The WateringSystem project includes hardware and software development for an ESP32-based plant watering controller. The system will monitor environmental conditions, control a water pump, and provide a web-based user interface for configuration and monitoring.

Within scope:
- Hardware selection and integration
- Firmware development for the ESP32 controller
- Web interface for system control and monitoring
- Basic scheduling and automation features

Out of scope:
- Mobile applications
- Integration with commercial smart home systems
- Water quality monitoring
- Fertilizer distribution

### 1.3 Project Context
- **Business or user needs addressed**: The system addresses the need for automated plant care to maintain healthy plants during absence, busy schedules, or for users who want to optimize plant growing conditions.
- **Relationship to other systems**: Standalone system with potential future expansion for smart home integration.
- **Environmental considerations**: Designed for indoor or covered outdoor use with access to a power source and water supply.
- **Budget and timeline constraints**: Focus on cost-effective components while ensuring reliability and safety.

### 1.4 Definitions and Acronyms
| Term | Definition |
|---|---|
| ESP32 | ESP32-WROOM-32E microcontroller used as the main control unit |
| BME280 | Environmental sensor for temperature and humidity measurements |
| LittleFS | Lightweight file system used for storing configuration and web files on the ESP32 |
| UI | User Interface |
| PCB | Printed Circuit Board |
| RS485 | Serial communication standard for long-distance and noise-resistant data transmission |
| Modbus | Communication protocol commonly used with industrial devices, including RS485 |
| EC | Electrical Conductivity, a measure of soil's ability to conduct electricity (related to nutrient content) |
| PH | Measure of soil acidity or alkalinity |
| NPK | Nitrogen, Phosphorus, and Potassium - primary nutrients for plants |
| TTL | Transistor-Transistor Logic, a digital logic standard |

## 2. System Description
The WateringSystem is an automated plant watering controller that uses environmental sensors to monitor conditions and control a water pump to maintain ideal moisture levels for plants. The system offers a web-based interface for monitoring and configuration.

### 2.1 Product Perspective
The WateringSystem operates as a standalone device that can be placed near plants requiring watering. It connects to the local network to provide a web interface accessible from any browser-capable device on the same network.

### 2.2 User Classes and Characteristics
- **Home gardeners**: Users with limited technical knowledge who want a simple solution for watering plants during absence.
- **Plant enthusiasts**: Users with specific knowledge of plant needs who want to fine-tune watering schedules and conditions.
- **System administrators**: Users with technical knowledge who will install and maintain the system.

### 2.3 Operating Environment
- **Hardware**: 
  - ESP32-WROOM-32E microcontroller
  - BME280 temperature and humidity sensor
  - Soil Moisture Temperature Humidity EC PH NPK sensor with RS485/Modbus interface
  - RS485 to TTL converter (high-quality alternative to MAX485)
  - 12V water pump with appropriate driver circuit
  - Power supply for both ESP32 and water pump
  - Water reservoir and tubing

- **Software**:
  - ESP32 firmware written in C/C++ using PlatformIO
  - Web interface using standard HTML/CSS/JavaScript
  - LittleFS for file storage on the ESP32
  - Modbus RTU protocol implementation for soil sensor communication

## 3. Functional Requirements
### 3.1 User Interface
- The system shall provide a web-based user interface accessible via standard browsers
- The UI shall display current environmental readings (temperature, humidity)
- The UI shall allow users to configure watering schedules
- The UI shall display system status and alert conditions
- The UI shall provide historical data of environmental conditions and watering events

### 3.2 Hardware Interface
- The system shall interface with a BME280 sensor via I2C protocol
- The system shall interface with the soil sensor via RS485/Modbus RTU protocol
- The system shall include a high-quality RS485 to TTL converter for reliable communication with the soil sensor
- The system shall control a 12V water pump via appropriate driver circuit for plant watering
- The system shall control a secondary 12V water pump for reservoir filling
- The system shall interface with water level sensors to monitor reservoir levels
- The system shall include status LEDs to indicate operation status
- The system shall include manual override buttons for direct control

### 3.3 Software Interface
- The firmware shall utilize the ESP32 Arduino core libraries
- The system shall implement Modbus RTU protocol for soil sensor communication
- The system shall use LittleFS for storing configuration and web files
- The system shall implement a lightweight web server for the user interface
- The system shall use ESPAsyncWebServer for handling HTTP requests asynchronously
- The system shall use form-data for critical control operations (e.g., watering control) to ensure reliable processing
- The system shall use JSON responses for status updates and configuration data

### 3.4 Communication Interfaces
- The system shall connect to local Wi-Fi networks
- The system shall serve web content via HTTP
- The system shall implement basic authentication for administrative functions
- The system shall provide the option for secure communications via HTTPS
- The system shall handle asynchronous web requests without blocking other system operations
- The system shall implement appropriate error handling for web communication failures

### 3.5 Software Development Requirements
- The system shall be developed using C++ with strict adherence to modern C++ standards
- The system firmware shall be developed using the PlatformIO ecosystem with Arduino framework
- The code shall follow object-oriented programming principles with proper use of constructors and destructors
- The system shall use interface-based design for all sensor and actuator components
- All hardware interactions shall be abstracted through interfaces to ensure modularity and testability
- Each sensor type shall have a dedicated interface that defines the standard interaction methods
- Concrete implementations of interfaces shall be provided for each physical sensor (BME280, RS485 soil sensor)
- The system shall use dependency injection principles to allow for easy component replacement and testing

## 4. Non-Functional Requirements
### 4.1 Performance
- The system shall respond to web interface requests within 2 seconds
- The system shall read sensor data at least once per minute
- The system shall be capable of controlling the pump with precision of at least 1 second

### 4.2 Reliability
- The system shall operate continuously for at least 6 months without requiring restart
- The system shall store configuration data in non-volatile memory
- The system shall recover from power outages without user intervention
- The system shall include watchdog functionality to detect and recover from software failures

### 4.3 Security
- The system shall implement basic authentication for administrative functions
- The system shall validate all user inputs to prevent injection attacks
- The system shall support firmware updates via the web interface
- The system shall provide options to restrict network access to the device

### 4.4 Usability
- The user interface shall be responsive and usable on mobile devices
- The system configuration shall be achievable without requiring technical knowledge
- The system shall provide clear status indicators for current operation
- The system shall notify users of error conditions via the web interface

### 4.5 Maintainability
- The firmware shall be modular to allow for easy component updates
- The system shall maintain logs of operations and errors
- The system shall provide a mechanism for backing up and restoring configuration
- The system shall be designed to allow for future sensor additions

### 4.6 Code Quality
- All code shall adhere to consistent coding style guidelines
- All code shall include appropriate documentation in English
- All interfaces shall be fully documented with function descriptions and parameter details
- The system shall maintain a high level of unit test coverage for all critical components
- All code shall be version controlled using Git
- Code reviews shall be conducted for all significant changes
- Memory management shall follow RAII principles (Resource Acquisition Is Initialization)
- The code shall avoid dynamic memory allocation where possible due to embedded constraints
- Error handling shall be consistent and robust throughout the codebase

## 5. System Features
### 5.1 Environmental Monitoring
- The system shall monitor ambient temperature and humidity using the BME280 sensor
- The system shall monitor soil conditions (moisture, temperature, humidity, EC, pH, NPK) using the RS485 soil sensor
- The system shall record and display trends of both ambient and soil environmental data
- The system shall allow for setting acceptable ranges for all environmental conditions
- The system shall alert when environmental conditions are outside acceptable ranges
- The system shall provide calibration options for the soil sensor measurements

### 5.2 Automated Watering
- The system shall control the water pump based on configurable schedules
- The system shall support time-based and sensor-based watering triggers
- The system shall use soil moisture readings as primary triggers for automated watering
- The system shall consider other soil parameters (EC, pH) when determining watering needs
- The system shall prevent overwatering through configurable limits
- The system shall provide manual override capabilities for immediate watering

### 5.3 Reservoir Management
- The system shall automatically maintain water levels in the main reservoir using a secondary pump
- The system shall use water level sensors to detect low and high water levels in the reservoir
- The system shall automatically start the reservoir pump when low water level is detected
- The system shall automatically stop the reservoir pump when high water level is detected
- The system shall include safety timeout functionality to prevent continuous pump operation
- The system shall allow manual control of the reservoir pump through the web interface
- The system shall provide status information about the reservoir water level and pump operation

### 5.3 Web Interface
- The system shall provide a responsive web interface accessible from the local network
- The system shall display current status and historical data via the web interface
- The system shall allow configuration changes through the web interface
- The system shall support data export via the web interface

## 6. Constraints
- The system must operate using the specified ESP32-WROOM-32E microcontroller
- The system must reliably communicate with the soil sensor via RS485 interface
- The system must use a high-quality RS485 to TTL converter instead of MAX485 for improved reliability
- The system must be powered by standard residential power supply
- The system must be designed with cost-effectiveness in mind
- The system must be safe to operate near water and electricity
- The firmware must operate within the memory constraints of the ESP32

## 7. Quality Attributes
- **Safety**: The system shall implement appropriate electrical isolation between water components and electronic components
- **Energy efficiency**: The system shall minimize power consumption during idle periods
- **Water efficiency**: The system shall optimize water usage through precise control based on soil moisture levels
- **Communication reliability**: The system shall implement error detection and recovery for RS485 communication
- **Measurement accuracy**: The system shall provide accurate soil measurements with appropriate calibration
- **Extensibility**: The system architecture shall support future addition of sensors and features

## 8. Appendices
### 8.1 Hardware Reference
Detailed specifications of the hardware components will be provided in the hardware.md document.

### 8.2 Safety Guidelines
Safety considerations for installation and operation will be detailed in the safety.md document.

## 9. Development Approach
### 9.1 Software Architecture
The system software shall follow a modular, layered architecture with the following components:
- **Hardware Abstraction Layer**: Interfaces and implementations for all hardware devices
- **Sensor Management**: Classes for reading, processing, and storing sensor data
- **Control Logic**: Decision-making components for watering and other actions
- **Communication Layer**: Web server and Modbus RTU protocol implementations
- **Storage Layer**: Configuration and data persistence using LittleFS
- **User Interface Layer**: Web-based interface for monitoring and control

### 9.2 Object-Oriented Design
- Each major component shall be represented by an abstract interface class
- Concrete implementations shall inherit from these interfaces
- Dependency injection shall be used to provide implementations to higher-level components
- Memory management shall follow RAII principles with proper use of constructors/destructors
- Standard C++ containers and algorithms shall be used where appropriate
- Static polymorphism (templates) shall be preferred over dynamic polymorphism where appropriate to reduce runtime overhead

### 9.3 Interface Examples
The system shall include interfaces such as:
- `ISensor`: Base interface for all sensors with methods for initialization, reading, and status
- `IActuator`: Base interface for all actuators with methods for control and status
- `IEnvironmentalSensor`: Interface for ambient condition sensors (extending ISensor)
- `ISoilSensor`: Interface for soil condition sensors (extending ISensor)
- `IWaterPump`: Interface for water pump control (extending IActuator)
- `IModbusDevice`: Interface for Modbus protocol communication devices
- `IDataStorage`: Interface for data persistence operations

### 9.4 Development Tools
- PlatformIO shall be used for project management, building, and deployment
- Git shall be used for version control
- Unit testing shall be implemented using appropriate C++ testing frameworks
- Static code analysis tools shall be used to ensure code quality
- Continuous integration shall be implemented to automate testing
- ESPAsyncWebServer shall be used for handling HTTP requests with proper error handling
- ArduinoJson shall be used for generating JSON responses (but not for receiving critical control inputs)

### 9.5 Coding Standards
- The code shall follow consistent naming conventions:
  - CamelCase for class names
  - camelCase for method and variable names
  - UPPER_CASE for constants
  - Interface classes shall be prefixed with 'I'
- All public methods shall include documentation comments
- Error handling shall use structured exception handling or error codes consistently
- The codebase shall minimize global variables and state
- All code shall be in English, including comments, variable names, and documentation

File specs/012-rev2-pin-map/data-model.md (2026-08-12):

# Data Model: board profile capability matrix

**Feature**: 012-rev2-pin-map · the "data" is compile-time facts.

## Capability flags and pins per board (target state)

| Capability flag | rev1 | rev1 pin | rev2 | rev2 pin | Change |
|---|---|---|---|---|---|
| `BOARD_HAS_RS485_DE` | 1 | 25 | 0 | — | none (existing) |
| `BOARD_HAS_RESERVOIR_PUMP` | 1 | 27 | 0 | — | none (existing) |
| `BOARD_HAS_INA226` | 0 | — | 1 | I2C 0x40 | none (existing) |
| `BOARD_HAS_BTN_MANUAL` | **1** | 5 | **0** | — | **new flag; rev2 pin removed** |
| `BOARD_HAS_BTN_CONFIG` | **1** | 18 | **0** | — | **new flag; rev2 pin removed** |
| `BOARD_HAS_VBAT_SENSE` | **0** | — | **1** | 34 (ADC1, input-only) | **new** |
| `BOARD_HAS_PWR_PG` | **0** | — | **1** | 35 (input-only, ext. pull-up) | **new** |
| `BOARD_HAS_SENS_PWR_EN` | **0** | — | **1** | 25 (output, rail OFF default) | **new** |

Unconditional pins (both boards, unchanged): I2C 21/22 · RS485 TX/RX 16/17 ·
MAIN_PUMP 26 · LEVEL_LOW/HIGH 32/33 · STATUS_LED 2. rev2-only constants
(unchanged): `BOARD_LEVEL_ACTIVE_LOW 1`, debounce 300 / settle 500 ms,
`BOARD_RS485_UART_PORT 2`.

## Invariants (compile-time enforced)

1. Flag = 1 ⟺ pin macro defined; flag = 0 ⟺ pin macro undefined
   (per flag, both boards — sanity `#error` pair each).
2. rev2: no defined `BOARD_PIN_*` ∈ expansion set {18, 19, 23, 4, 27}.
3. Note: rev1 legitimately violates (2) — BTN_CONFIG=18, RESERVOIR_PUMP=27 —
   the expansion reservation is a **rev2-only** invariant; the check must be
   inside the rev2 conditional.
4. All pin-distinctness checks already in the sanity section remain and must
   still pass with the new definitions (25 appears on rev1 as RS485_DE and on
   rev2 as SENS_PWR_EN — never both in one target).

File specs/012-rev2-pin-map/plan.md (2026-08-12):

# Implementation Plan: rev2 board profile aligned with frozen hardware

**Branch**: `fix/rev2-pin-map` | **Date**: 2026-08-12 | **Spec**: [spec.md](spec.md)

**Input**: Feature specification from `specs/012-rev2-pin-map/spec.md`

## Summary

Close the gap between the frozen rev2 hardware (schematic freeze 2026-08-12)
and the firmware's rev2 board profile: remove the phantom button pins (one of
which sits on the expansion header's SPI clock and is polled at boot), add the
three missing frozen signals behind capability flags, and retire the stale
SYNC1 markers — using the established `BOARD_HAS_*` + deliberate-undefine
enforcement pattern, extended contract tests, and zero behavioral change on
rev1.

## Technical Context

**Language/Version**: C/C++ (C17 / C++17), ESP-IDF v6.0.1 (pinned Docker image)

**Primary Dependencies**: ESP-IDF GPIO/Kconfig only — no new components

**Storage**: N/A

**Testing**: host test app (`firmware/test_apps/host`, CMake + pinned
toolchain in CI), compile-time contract TUs per board target

**Target Platform**: ESP32 (rev1 devkit / rev2 custom PCB via
`CONFIG_BOARD_REV1_DEVKIT` / `CONFIG_BOARD_REV2`)

**Project Type**: embedded firmware, single repo

**Performance Goals**: N/A (compile-time facts; no runtime additions)

**Constraints**: pumps-OFF-at-boot invariant untouchable (constitution I);
rev1 behavior byte-equivalent; no hardware available for verification —
everything must be provable by build + host tests

**Scale/Scope**: 1 header, 1 boot file, 2 contract-test TUs, docs citations.
No new files except tests if split is cleaner.

## Constitution Check

*GATE: evaluated pre-Phase 0 and re-checked post-design — PASS on both.*

| Principle | Verdict | Note |
|---|---|---|
| I Safety First | PASS | Boot pump-OFF logic untouched on both boards; button-path guard removes a spurious-provisioning risk. No fail-safe weakened. |
| II Host-Testability | PASS | All new facts are compile-time; contract TUs extended; no hardware needed. |
| III Reproducible Builds | PASS | No dependency changes; CI already builds both targets. |
| IV Frozen Legacy | PASS | Arduino tree untouched. |
| V Checkpoint-Gated Workflow | PASS | CP1 passed silently; this plan stops at CP2 before implementation. |
| VI (remaining principles) | PASS | No scope beyond profile alignment. |

## Project Structure

### Documentation (this feature)

```text
specs/012-rev2-pin-map/
├── spec.md
├── plan.md              # this file
├── research.md          # R1–R6: survey, mechanism decision, consumers
├── data-model.md        # capability-flag/pin matrix for both boards
├── quickstart.md        # build/test validation commands
├── contracts/
│   └── board-profile-contract.md
├── checklists/requirements.md
└── tasks.md             # /speckit-tasks output (next step)
```

### Source Code (repository root)

```text
firmware/
├── components/board/include/board/board.h    # the profile — main edit
├── main/app_main.cpp                         # guard config-button block
└── test_apps/host/main/
    ├── test_board_contract_rev1.cpp          # extend: buttons present, new flags 0
    └── test_board_contract_rev2.cpp          # extend: buttons absent, new pins, expansion disjointness
```

**Structure Decision**: existing layout; no new components. The board profile
stays a single header per the project rule "pin tables live in
`firmware/components/board/` only".

## Design

### D1 — board.h rev2 section (per research R1/R2)

1. Remove `BOARD_PIN_BTN_MANUAL` / `BOARD_PIN_BTN_CONFIG` from rev2; add
   `BOARD_HAS_BTN_MANUAL` / `BOARD_HAS_BTN_CONFIG` **to both sections**
   (rev1 = 1 with existing pins 5/18 unchanged; rev2 = 0, pins undefined).
2. Add to rev2 (with `BOARD_HAS_* 1`), absent from rev1 (`BOARD_HAS_* 0`):
   - `BOARD_PIN_VBAT_SENSE 34` — input-only, ADC1 (FW-1: nonlinearity note
     stays in rev2-firmware-notes; the profile carries pin + ADC1-only fact)
   - `BOARD_PIN_PWR_PG 35` — input-only, open-drain + external pull-up, no
     internal pulls on IO34–39 (FW-6)
   - `BOARD_PIN_SENS_PWR_EN 25` — output, sensor rail OFF default
3. Replace all 11 `TODO(SYNC1)` markers and the "provisionally mirror rev 1"
   header with citations: `02-mcu.md §2.2 SYNC 1 map (frozen 2026-08-12)`.
4. Update the I²C address-map comment: 0x41 = solar INA226, populated on this
   node (support lands PR-14). Address constant for it NOT added — PR-14 owns
   the driver surface.
5. Sanity section: flag↔pin consistency checks for the five new flags (same
   pattern as reservoir pump), plus rev2-only expansion-reservation check —
   compile error if any defined `BOARD_PIN_*` ∈ {18, 19, 23, 4, 27}.

### D2 — app_main.cpp (per research R3)

Wrap the config-button provisioning block (`gpio_config` of BTN_CONFIG, the
poll loop, its LED feedback) in `#if BOARD_HAS_BTN_CONFIG`. The
credentials-absent provisioning path is unconditional and untouched. Pump
boot-safety code untouched.

### D3 — contract tests (per research R4)

- rev1 TU: `BOARD_HAS_BTN_CONFIG == 1`, `BOARD_PIN_BTN_CONFIG == 18`,
  `BOARD_HAS_BTN_MANUAL == 1`, pin 5; new signal flags all 0 and pins
  undefined (`#ifdef` + `#error`).
- rev2 TU: button flags 0, pins undefined; `BOARD_PIN_VBAT_SENSE == 34`,
  `BOARD_PIN_PWR_PG == 35`, `BOARD_PIN_SENS_PWR_EN == 25`, flags 1;
  static_assert that every defined core pin ∉ expansion set (belt to the
  header's braces — catches accidental future edits even if the header check
  is removed).
- Grep-style truth checks (zero `TODO(SYNC1)`) are a CI/test-script concern:
  add a trivial host test or CI step ONLY if cheap; otherwise SC-004 is
  verified at review. (Tasks phase decides; do not over-engineer.)

### D4 — docs

`firmware/CLAUDE.md` board section: note the five new capability flags and
the frozen-map citation convention, if that file documents the profile (check
at implementation; keep diff minimal).

## Complexity Tracking

No constitution violations. No new mechanisms — the feature deliberately
reuses the existing enforcement pattern (research R2 rejected the
`BOARD_PUMP_COUNT` alternative as a second parallel mechanism).

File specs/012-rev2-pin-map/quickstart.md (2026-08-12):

# Quickstart: validate feature 012

All validation is host-side + containerized builds — no hardware. Commands
below mirror `.github/workflows/firmware-build.yml` (the canonical forms).

## 1. Host test suite (contract TUs compile the real header)

```bash
cd firmware/test_apps/host
idf.py --preview set-target linux
idf.py build
./build/pump_host_tests.elf
```

Expected: build succeeds (the contract TUs are compile-time — a contract
violation IS a build failure) and the runtime suite passes with no
regressions.

## 2. Both board targets, pinned container

```bash
docker run --rm -v "$PWD/firmware":/project -w /project espressif/idf:v6.0.1 \
  idf.py -DSDKCONFIG_DEFAULTS="sdkconfig.defaults;sdkconfig.board.rev1_devkit" build
docker run --rm -v "$PWD/firmware":/project -w /project espressif/idf:v6.0.1 \
  idf.py -DSDKCONFIG_DEFAULTS="sdkconfig.defaults;sdkconfig.board.rev2" build
```

(CI additionally greps `firmware/sdkconfig` for `CONFIG_BOARD_REV1_DEVKIT=y` /
`CONFIG_BOARD_REV2=y` to prove the right profile was built — do the same if
building both locally back-to-back, and clean between runs so the second
build does not inherit the first's sdkconfig.)

## 3. Truth checks (SC-004)

```bash
grep -rn "TODO(SYNC1)\|provisionally" firmware/components/board/ && echo FAIL || echo OK
```

## 4. Negative proof (optional, high-value)

Temporarily add an unguarded `BOARD_PIN_BTN_CONFIG` reference to the rev2
contract TU — the host build must FAIL. Revert. (Demonstrates the enforcement
pattern actually bites; the rev1 TU documents this technique.)

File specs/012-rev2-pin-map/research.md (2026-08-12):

# Research: rev2 board profile aligned with frozen hardware

**Date**: 2026-08-12 · **Feature**: 012-rev2-pin-map

## R1 — What is actually divergent on origin/main (survey result)

**Decision basis for the whole feature.** The initial assumption (reservoir
pump on IO27 still defined for rev2) was FALSE — fixed in feature 006 with
`BOARD_HAS_RESERVOIR_PUMP`, deliberate pin-undefine enforcement, guarded
app_main, and contract tests. Verified divergences that remain:

| # | Divergence | Evidence |
|---|---|---|
| 1 | Phantom buttons: rev2 defines `BOARD_PIN_BTN_MANUAL 5`, `BOARD_PIN_BTN_CONFIG 18`; neither exists on frozen rev2 (only BOOT/RESET); IO18 = `EXP_SCK` | `board.h` rev2 section; `02-mcu.md` §2.2 SYNC 1 map; `08-expansion.md` |
| 2 | Boot path reads the phantom button: `app_main.cpp` configures IO18 as input and polls it (with STATUS_LED feedback) to enter provisioning | `app_main.cpp:148-217` |
| 3 | Missing signals: `VBAT_SENSE` (IO34), `PWR_PG` (IO35), `SENS_PWR_EN` (IO25) undefined | grep over `board.h`; `01-power.md` §1.0a; `rev2-firmware-notes.md` FW-1/FW-6 |
| 4 | 11 stale `TODO(SYNC1)` markers + "provisionally mirror rev 1" header | grep count |
| 5 | Stale comment: I²C map calls 0x41 "solar footprint, DNP"; solar group is populated per the 2026-06-20 decision (gate cleared 2026-08-10) | `board.h` rev2 INA226 block; `01-power.md` §1.5 |

All present rev2 pin VALUES verified correct against the frozen contract
(I2C 21/22, RS485 16/17, pump 26, level 32/33, LED 2). The fix is
subtractive/additive, not corrective, for existing values.

## R2 — Mechanism for board-conditional peripherals

**Decision**: per-peripheral capability flags (`BOARD_HAS_*`) with the
deliberate-undefine enforcement pattern.

**Rationale**: the codebase already settled this twice — `BOARD_HAS_RS485_DE`
(feature 004) and `BOARD_HAS_RESERVOIR_PUMP` (feature 006), both with the
"flag 0 ⇒ pin macro undefined ⇒ unguarded reference is a compile error"
pattern, sanity-checked in the header's consistency section and pinned by the
contract-test TUs. Introducing `BOARD_PUMP_COUNT` (the alternative floated at
spec time) would add a second parallel mechanism for the same job.

**Alternatives considered**: `BOARD_PUMP_COUNT` — rejected: pumps already use
the HAS-flag pattern on origin/main; a count adds nothing the flag doesn't
give and invites index-loop code over pins that don't form an array.

**New flags this feature adds**: `BOARD_HAS_BTN_MANUAL`, `BOARD_HAS_BTN_CONFIG`
(rev1 = 1, rev2 = 0); `BOARD_HAS_VBAT_SENSE`, `BOARD_HAS_PWR_PG`,
`BOARD_HAS_SENS_PWR_EN` (rev1 = 0, rev2 = 1). Flags are defined 0/1 on BOTH
boards (never absent) so `#if` works uniformly; pin macros exist only where
flag = 1.

## R3 — Consumers that must become conditional

Grep survey of `BOARD_PIN_BTN_*` / `BOARD_PIN_STATUS_LED` outside board.h:

- `app_main.cpp:148-217` — config-button provisioning entry (IO18 input cfg,
  poll loop, LED feedback). Must be `#if BOARD_HAS_BTN_CONFIG`. The
  credentials-absent provisioning path is separate and stays unconditional.
- `wifi_task.cpp/h` — STATUS_LED only; LED exists on both boards; no change.
- `BOARD_PIN_BTN_MANUAL` — **zero consumers** outside board.h. Removing the
  rev2 definition breaks nothing.

## R4 — Where the contract is enforced

- `firmware/test_apps/host/main/test_board_contract_rev{1,2}.cpp`: each TU
  defines `CONFIG_BOARD_REVx 1` and includes the REAL `board/board.h`,
  pinning values/absences with `static_assert` / `#ifdef` + `#error`. The
  natural home for every new assertion (buttons, new signals, expansion
  disjointness).
- `board.h` sanity section: compile-time distinctness and flag/pin
  consistency checks; gains (a) flag↔pin consistency for the five new flags,
  (b) a rev2-only expansion-reservation check asserting no defined core pin
  equals 18/19/23/4/27.
- CI already builds both targets + host suite (constitution III).

## R5 — Expansion-set reservation as compile-time property (SC-002)

**Decision**: express "boot-claimed ⊆ profile ∧ profile ∩ expansion = ∅" in
the header's sanity section: on rev2, `#if` chains erroring if any defined
`BOARD_PIN_*` equals an expansion GPIO. Boot code derives every claimed pin
from `BOARD_PIN_*` macros (it already does), so header-level disjointness +
guarded button path together give the SC-002 property without runtime cost.

**Alternative considered**: runtime assertion table — rejected: adds code to
the safety-critical boot path for a property fully decidable at compile time.

## R6 — Provisioning UX on buttonless rev2

**Decision**: accept credentials-absent as the only rev2 provisioning
trigger (spec assumption, flagged to Paul at CP2). BOOT-button (IO0) reuse
after boot is feasible ESP32 practice but is new function on a frozen-scope
fix — deferred to PR-14+.

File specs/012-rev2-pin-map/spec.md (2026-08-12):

# Feature Specification: rev2 board profile aligned with frozen hardware

**Feature Branch**: `fix/rev2-pin-map`

**Created**: 2026-08-12

**Status**: Draft (rewritten same day after codebase survey — see Revision note)

**Input**: User description: "Align the rev2 board profile in firmware/components/board/include/board/board.h with the frozen rev2 hardware design. Close the stale SYNC1 markers, remove phantom peripherals, add the missing frozen signals, keep the pumps-OFF-at-boot invariant intact on both boards."

## Revision note

The first draft of this spec assumed the rev2 profile still defined two pump
channels with a reservoir pump on IO27. A survey of `origin/main` (the branch
this feature builds on) showed that fix already landed during phases 1–3:
`BOARD_HAS_RESERVOIR_PUMP == 0` on rev2, the pin macro deliberately undefined,
boot safety properly guarded, host contract tests in place
(`test_board_contract_rev1/rev2.cpp`). The earlier observation came from a
stale working tree. This spec covers what actually remains divergent.

## Context

The rev2 hardware design was frozen 2026-08-12 (all 8 schematic sheets drawn,
ERC clean, components ordered). Surveying the current rev2 board profile
against the frozen design leaves three real divergence classes:

1. **A boot-active phantom peripheral (the serious one).** The profile defines
   `BOARD_PIN_BTN_CONFIG = 18` and `BOARD_PIN_BTN_MANUAL = 5`, and the boot
   sequence configures IO18 as an input and reads it to decide whether to
   enter WiFi provisioning mode. On frozen rev2 hardware **neither button
   exists** (the board has only BOOT/RESET switches on IO0/EN and a status
   LED on IO2), and **IO18 is `EXP_SCK`** — the expansion header's SPI clock
   (J7, reserved set IO18/19/23/4/27). Consequences on real rev2 hardware:
   whatever an attached expansion device does with SCK can be misread as
   "operator holds the config button" and drop the node into provisioning
   mode at boot; and core firmware claims a pin the design reserves for
   expansion.
2. **Missing frozen signals.** Three signals the frozen design provides have
   no definition: battery-voltage sense (IO34, ADC1, input-only), buck
   power-good (IO35, input-only, open-drain with external pull-up), and
   sensor-rail enable (IO25, output, rail OFF by default).
3. **Stale annotations.** Eleven "TODO(SYNC1)" markers and a section header
   saying the pin map "provisionally mirrors rev 1" — but SYNC 1 (the pin-map
   freeze) has happened and every present value matches the frozen contract.
   Also one stale hardware comment: the I²C address-map note calls the solar
   INA226 (0x41) "footprint, DNP", but the populate decision of 2026-06-20
   (gate cleared 2026-08-10, `01-power.md` §1.5) made it a populated device
   on this node.

Already correct on `origin/main` — to be regression-guarded, not re-done:
single-pump profile with compile-error enforcement, level-sensor polarity and
timing constants (active LOW, 300/500 ms), pump INA226 at 0x40, status LED on
IO2 (matches the frozen design), and the existing board contract host tests.

Sources of truth: `hardware/rev2/design-notes/02-mcu.md` §2.2 (SYNC 1 GPIO
map) and `00-architecture.md` §0.5 pin contract (both on the
`docs/single-pump-node` branch), `docs/rev2-firmware-notes.md` FW-1..FW-6,
`docs/parity-checklist.md` for rev1.

### Frozen rev2 pin facts (the contract this feature encodes)

| Signal | GPIO | Direction / note |
|---|---|---|
| I2C SDA / SCL | IO21 / IO22 | bidirectional; 3 devices: BME280 0x77, INA226 0x40 (pump), INA226 0x41 (solar, populated) |
| RS485 TX / RX | IO16 / IO17 | auto-direction transceiver, no DE pin |
| Pump enable (single pump) | IO26 | active-HIGH output *(already correct)* |
| Reservoir level LOW / HIGH | IO32 / IO33 | inputs, active LOW *(already correct)* |
| Status LED | IO2 | output *(already correct)* |
| Sensor-rail enable | IO25 | output; switched 12 V sensor domain, OFF by default — **missing today** |
| Battery voltage sense | IO34 | input-only, ADC1; ADC2 unusable with WiFi — **missing today** |
| Buck power-good | IO35 | input-only, open-drain externally pulled up; IO34–39 have no internal pulls — **missing today** |
| Manual / config buttons | — | **do not exist on rev2** (BOOT/RESET only) — profile must say so |
| Expansion (reserved, untouchable) | IO18/19/23/4/27 | J7: VSPI SCK=IO18, MISO=IO19, MOSI=IO23, CS=IO4, IRQ=IO27 (`08-expansion.md` §8.3); core firmware must not claim any of them |

## User Scenarios & Testing *(mandatory)*

### User Story 1 - rev2 boot touches only pins that exist on rev2 (Priority: P1)

Paul boots the firmware on rev2 hardware (module prototype or final PCB) with
an expansion device attached to J7. The node never claims an expansion pin and
never mistakes expansion-bus activity for a pressed configuration button.

**Why this priority**: This is the correctness- and hardware-protecting fix.
Today's boot path reads `EXP_SCK` as if it were a button — a spurious
provisioning entry at best, interference with attached expansion hardware at
worst, on a project whose failure history is exactly "pins used for something
the hardware didn't intend".

**Independent Test**: Host contract tests for the rev2 target assert the
button macros are absent (unguarded reference fails to compile) and that the
boot path's claimed-pin set is disjoint from the expansion set.

**Acceptance Scenarios**:

1. **Given** the rev2 board target, **When** the firmware boots, **Then** no
   GPIO in the expansion set IO18/19/23/4/27 is configured (input or output)
   or read by core firmware.
2. **Given** the rev2 board target with no stored WiFi credentials, **When**
   the firmware boots, **Then** provisioning mode is entered via the
   credentials-absent path exactly as before — the button path simply does
   not exist on this board.
3. **Given** the rev1 board target, **When** the firmware boots, **Then** the
   config-button check on IO18, the manual button on IO5, and both pump
   outputs behave exactly as today — rev1 has this hardware and must not
   change.

---

### User Story 2 - the profile states every frozen rev2 signal (Priority: P2)

A developer (human or agent) implementing the rev2 bring-up drivers (PR-14)
reads the board profile and finds every signal the frozen hardware provides —
battery sense, power-good, sensor-rail enable — with direction and polarity
constraints, without opening the schematic.

**Why this priority**: The board profile is the single place pin facts live
(project rule: pin tables are not duplicated elsewhere). Missing entries force
the next developer back to the schematic and invite guessed constants.

**Independent Test**: rev2 contract test asserts the three new definitions
exist with the frozen values; rev1 contract test asserts referencing them
unguarded fails to compile.

**Acceptance Scenarios**:

1. **Given** the rev2 board target, **When** a driver references battery
   sense, power-good, or sensor-rail enable, **Then** the definitions exist
   with the frozen GPIO numbers (IO34, IO35, IO25) and capability flags.
2. **Given** the rev1 board target, **When** the same references are made
   unguarded, **Then** compilation fails (rev1 lacks all three) — the
   established enforcement pattern.

---

### User Story 3 - annotations tell the truth (Priority: P3)

A reader of the rev2 profile sees no stale "TODO(SYNC1)" markers, no
"provisionally mirrors rev 1" language, and no "solar INA226 is DNP" claim;
each section instead cites the frozen design source.

**Why this priority**: Stale TODOs actively invite "helpful" future edits to
values that are frozen, and the DNP claim contradicts a purchasing decision
already made.

**Independent Test**: Text search over the board component returns zero
occurrences of "TODO(SYNC1)" and "provisionally"; the I²C address-map comment
describes 0x41 as populated on this node.

**Acceptance Scenarios**:

1. **Given** the merged feature, **When** searching the board component for
   SYNC1 markers or provisional wording, **Then** none remain in the rev2
   section and each pin group cites its design-note source.

---

### Edge Cases

- Watchdog/panic/OTA reset (not cold boot): the boot path runs the same
  claiming logic — the expansion-untouched and single-pump guarantees hold on
  every reset type.
- rev2 provisioning re-entry on a deployed node: with the button path absent,
  re-provisioning relies on the credentials-absent path and whatever
  API/reset mechanisms PR-07 provides. If a physical re-provisioning trigger
  is wanted on rev2, the BOOT button (IO0) is free after boot — that is a
  future feature (PR-14 or later), explicitly out of scope here.
- A future board with different button complement must be expressible via the
  capability flags without touching application logic.

## Requirements *(mandatory)*

### Functional Requirements

- **FR-001**: The rev2 board profile MUST NOT define manual- or config-button
  pins; button presence MUST be a capability flag, and an unguarded reference
  to an absent button pin MUST fail compilation (established enforcement
  pattern).
- **FR-002**: The rev1 board profile MUST remain behaviorally identical: all
  existing rev1 pin values, both buttons, both pumps, unchanged.
- **FR-003**: The boot provisioning-entry logic MUST compile the button path
  only on boards that have a config button; on buttonless boards the
  credentials-absent trigger (existing PR-07 behavior) is the sole entry and
  MUST be preserved unchanged.
- **FR-004**: On rev2, core firmware MUST NOT configure, drive, or read any
  GPIO in the expansion set (IO18, IO19, IO23, IO4, IO27).
- **FR-005**: The rev2 profile MUST define battery-voltage sense (IO34,
  ADC1, input-only), buck power-good (IO35, input-only, externally pulled
  up), and sensor-rail enable (IO25, output, rail OFF default), each behind a
  capability flag with the compile-error enforcement pattern on boards that
  lack the signal.
- **FR-006**: All "TODO(SYNC1)" markers and provisional wording MUST be
  removed from the board component; each rev2 pin group MUST cite its frozen
  design source; the solar INA226 comment MUST reflect the populate decision
  (0x41 populated on this node; firmware support for reading it is PR-14
  scope).
- **FR-007**: Host contract tests MUST be extended to cover: button absence
  on rev2 / presence on rev1, the three new rev2 signals, and the
  expansion-set-disjointness of boot-claimed pins; existing pump-invariant
  tests MUST remain green unchanged.
- **FR-008**: Both board targets MUST build green in CI from a clean
  checkout; the host test suite MUST pass.

### Key Entities

- **Board profile**: per-target pin definitions and capability flags; the
  single source of pin truth in firmware.
- **Boot-claimed pin set**: every GPIO the boot path configures or reads on a
  target; must be derivable from the profile and disjoint from the expansion
  set on rev2.
- **Expansion pin set**: IO18/19/23/4/27 — reserved for J7, unclaimed by core
  firmware on rev2.

## Success Criteria *(mandatory)*

### Measurable Outcomes

- **SC-001**: Host contract tests pass asserting: rev2 defines no button
  pins, defines the three new signals with frozen values, and rev1 values are
  unchanged.
- **SC-002**: The rev2 boot path's claimed-pin set is provably disjoint from
  IO18/19/23/4/27 (compile-time assertion or host test).
- **SC-003**: CI builds both board targets green on the feature branch; host
  suite passes.
- **SC-004**: Zero "TODO(SYNC1)" and zero "provisionally" occurrences remain
  in the board component.
- **SC-005**: The rev2 profile covers all rows of the frozen pin facts table
  (present signals defined, absent peripherals capability-flagged off).

## Assumptions

- The frozen pin facts table is correct and final, extracted from
  `02-mcu.md` §2.2 SYNC 1 map and the §0.5 pin contract after the 2026-08-12
  freeze. Future pin changes go schematic-first and re-open the profile
  deliberately.
- Consuming the new signal definitions (ADC reads, PG monitoring, rail
  switching, solar INA226 support) is PR-14 driver scope; this feature only
  makes the facts available and safe.
- Losing the physical config-button provisioning trigger on rev2 is accepted:
  the hardware has no such button, and the credentials-absent path covers
  first provisioning. A BOOT-button-based trigger is a possible future
  feature, out of scope.
- The legacy Arduino tree is frozen and untouched.
- No hardware is required for verification; host tests + CI builds suffice.
  Bench verification lands with PR-14 bring-up.

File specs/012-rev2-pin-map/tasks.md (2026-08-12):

# Tasks: rev2 board profile aligned with frozen hardware

**Input**: Design documents from `specs/012-rev2-pin-map/`
**Prerequisites**: plan.md (D1–D4), research.md (R1–R6), data-model.md (capability matrix), contracts/board-profile-contract.md

**Tests**: Included — the contract tests ARE the feature's verification
(constitution II; spec FR-007). Ordering is test-first: contract assertions
are written before the header edits that make them pass; a red step is a
build failure, which is the intended TDD signal for compile-time contracts.

**Organization**: By user story, in spec priority order. All stories touch
`board.h` and the contract TUs, so tasks run sequentially (same files — no
[P] markers except the truly independent docs task).

## Phase 1: Setup

- [x] T001 Record the green baseline: run the host test suite and both board-target builds per `specs/012-rev2-pin-map/quickstart.md` §1–2 on the unmodified branch; note results in the task log. A pre-existing red here is a STOP — this feature must start from green.

## Phase 2: Foundational

*(No blocking infrastructure — single-header feature. Proceed to stories.)*

## Phase 3: User Story 1 — rev2 boot touches only pins that exist (P1)

**Goal**: remove the phantom buttons (BTN_CONFIG on EXP_SCK/IO18 polled at
boot), guard the boot provisioning button path, reserve the expansion set.

**Independent test**: host build fails if rev2 defines a button pin or any
core pin collides with the expansion set; app_main compiles for rev2 without
the button block and for rev1 with it, unchanged.

- [x] T002 [US1] Extend `firmware/test_apps/host/main/test_board_contract_rev2.cpp`: assert `BOARD_HAS_BTN_MANUAL == 0` and `BOARD_HAS_BTN_CONFIG == 0`; `#ifdef BOARD_PIN_BTN_MANUAL/`BOARD_PIN_BTN_CONFIG` → `#error`; add static_asserts that every defined core `BOARD_PIN_*` (I2C, RS485, pump, levels, LED — and the US2 signals once they exist) differs from each of 18, 19, 23, 4, 27. Expect the build to go red (pins still defined).
- [x] T003 [US1] Extend `firmware/test_apps/host/main/test_board_contract_rev1.cpp`: assert `BOARD_HAS_BTN_MANUAL == 1`, `BOARD_PIN_BTN_MANUAL == 5`, `BOARD_HAS_BTN_CONFIG == 1`, `BOARD_PIN_BTN_CONFIG == 18` — pins rev1 genuinely has, values frozen (FR-002 regression guard). Document in the TU comment that the expansion reservation is rev2-only (rev1 legitimately uses 18/27 — data-model invariant 3).
- [x] T004 [US1] Edit `firmware/components/board/include/board/board.h`: add `BOARD_HAS_BTN_MANUAL 1` / `BOARD_HAS_BTN_CONFIG 1` to the rev1 section above the existing pins; in the rev2 section set both flags 0 and DELETE both pin defines (deliberate-undefine pattern, comment mirroring the RS485_DE/reservoir-pump wording).
- [x] T005 [US1] Edit `firmware/components/board/include/board/board.h` sanity section: add flag↔pin consistency `#error` pairs for both button flags (pattern of lines 211–217); add the rev2-only expansion-reservation check (`#if`-chain erroring if any defined core pin ∈ {18,19,23,4,27}), placed inside a `CONFIG_BOARD_REV2` conditional per data-model invariant 3.
- [x] T006 [US1] Edit `firmware/main/app_main.cpp`: wrap the config-button provisioning block (input `gpio_config` of `BOARD_PIN_BTN_CONFIG`, the poll loop and its STATUS_LED feedback, approx. lines 148–217) in `#if BOARD_HAS_BTN_CONFIG`; the credentials-absent provisioning path and all pump boot-safety code stay untouched. Update the block comment to state why (no button on rev2; IO18 is EXP_SCK).
- [x] T007 [US1] Validate US1: host suite green, both board targets build green (quickstart §1–2).

**Checkpoint**: US1 delivers the safety/correctness fix on its own.

## Phase 4: User Story 2 — profile states every frozen signal (P2)

**Goal**: add VBAT_SENSE (IO34), PWR_PG (IO35), SENS_PWR_EN (IO25) behind
capability flags.

**Independent test**: rev2 TU asserts the three pins/flags; rev1 TU proves
unguarded references cannot compile on rev1.

- [x] T008 [US2] Extend `firmware/test_apps/host/main/test_board_contract_rev2.cpp`: assert `BOARD_HAS_VBAT_SENSE == 1` / `BOARD_PIN_VBAT_SENSE == 34`, `BOARD_HAS_PWR_PG == 1` / `BOARD_PIN_PWR_PG == 35`, `BOARD_HAS_SENS_PWR_EN == 1` / `BOARD_PIN_SENS_PWR_EN == 25`; fold the three pins into the T002 expansion-disjointness asserts. Red until T010.
- [x] T009 [US2] Extend `firmware/test_apps/host/main/test_board_contract_rev1.cpp`: assert all three flags are `== 0` and pins undefined (`#ifdef` → `#error`) on rev1.
- [x] T010 [US2] Edit `firmware/components/board/include/board/board.h`: rev1 section — three flags at 0; rev2 section — three flags at 1 with pins 34/35/25 and constraint comments (IO34 input-only ADC1, ADC2 dead with WiFi, FW-1 pointer; IO35 input-only, open-drain + external pull-up, no internal pulls IO34–39, FW-6; IO25 output, sensor rail OFF default, FW-3 settle owned by PR-14). Add the three flag↔pin sanity pairs; confirm the pin-distinctness checks still pass (25 = RS485_DE on rev1 vs SENS_PWR_EN on rev2 — never same target).
- [x] T011 [US2] Validate US2: host suite green, both board targets build green.

**Checkpoint**: PR-14 driver work now has every frozen fact available.

## Phase 5: User Story 3 — annotations tell the truth (P3)

**Goal**: zero stale markers; citations in; solar comment corrected.

**Independent test**: quickstart §3 grep returns nothing.

- [x] T012 [US3] Edit `firmware/components/board/include/board/board.h`: delete all 11 `TODO(SYNC1)` markers and the "GPIO numbers provisionally mirror rev 1…" header sentence; each rev2 pin group cites `hardware/rev2/design-notes/02-mcu.md §2.2 SYNC 1 map (frozen 2026-08-12)` once, group-level not per-line; update the I²C address-map comment: `0x41 solar INA226 — populated on this node (decision 2026-08-12; driver support PR-14)`, BME280 = 0x77.
- [x] T013 [US3] Validate US3: `grep -rn "TODO(SYNC1)\|provisionally" firmware/components/board/` returns nothing (quickstart §3); host suite + both targets still green.

## Phase 6: Polish & cross-cutting

- [x] T014 [P] Check `firmware/CLAUDE.md` board-profile documentation (plan D4): if it enumerates capability flags or the pin-table convention, add the five new flags and the frozen-map citation convention; if it doesn't document the profile, change nothing.
- [x] T015 Negative proof (quickstart §4): temporarily add an unguarded `BOARD_PIN_BTN_CONFIG` use to the rev2 TU, confirm the build FAILS, revert. Record in the implementation notes.
- [x] T016 Full quickstart pass (§1–3) as the feature's final gate; assemble the implementer's test checklist for CP3 (host-test PR — CI suite is the verifier; no HIL needed, note the deferred bench verification lands in PR-14).

## Dependencies & execution order

- T001 → everything (green baseline gate).
- US1 (T002–T007) → US2 (T008–T011): same files, and T008 folds new pins
  into T002's disjointness list. US2 → US3 (T012–T013): comment edits land
  last so citations describe the final content. Polish last; T014 is [P]
  (different file, no dependency).
- MVP scope: **US1 alone** — the safety/correctness fix stands on its own if
  implementation must stop early.

## Implementation strategy

Test-first per story: write the contract assertions (red = build failure),
make them green with the header/app edit, validate, move on. Every task's
"green" is machine-checkable (build result or grep), so the implementer can
self-verify without judgment calls. Commit granularity: one commit per story
phase (see CLAUDE.md one-branch-at-a-time rule; commits stay on
fix/rev2-pin-map in the worktree).

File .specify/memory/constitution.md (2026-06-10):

<!--
Sync Impact Report
- Version change: (template, unversioned) → 1.0.0 (initial ratification)
- Modified principles: n/a (initial adoption)
- Added sections: Core Principles (I–VI), Additional Constraints, Development Workflow, Governance
- Removed sections: none (template placeholders replaced)
- Templates requiring updates:
  ✅ .specify/templates/plan-template.md — generic Constitution Check gate, compatible as-is
  ✅ .specify/templates/spec-template.md — no constitution-specific tokens, compatible as-is
  ✅ .specify/templates/tasks-template.md — test-first task ordering aligns with Principle II, compatible as-is
- Follow-up TODOs: none
-->

# WateringSystem Constitution

## Core Principles

### I. Safety First (NON-NEGOTIABLE)

Pumps MUST be off at boot, after any reset (watchdog, brownout, panic), and across
OTA restarts — driving pump GPIOs to a safe OFF state is the first action of the
firmware. Invalid, stale, or missing sensor data in automatic mode MUST force a pump
stop. Manual mode is an explicit operator override and is the only path that bypasses
sensor-validity checks. All fail-safe behaviors are enumerated in
`docs/parity-checklist.md` and every one of them MUST be covered by host tests.
No feature, refactor, or optimization may weaken a fail-safe behavior; WiFi or
network failure MUST never affect watering safety.

### II. Host-Testability

All application logic — watering control, scheduling, safety conditions, reservoir
management — MUST be testable on the host against mock implementations. Hardware
access happens only behind the interface layer (`ISensor`, `IEnvironmentalSensor`,
`ISoilSensor`, `IActuator`, `IWaterPump`, `IModbusClient`, `IDataStorage`).
Code that touches IDF hardware APIs directly belongs in driver components that
implement these interfaces and contain no business logic. The host test suite runs
in CI on every push; watering logic and safety conditions target 100% host coverage.

### III. Reproducible Builds

The toolchain and every dependency are pinned: ESP-IDF v6.0.1 via the
`espressif/idf` Docker image in both local and CI builds, exact component versions
in `idf_component.yml` (with `dependencies.lock` tracked), and exact PlatformIO
platform/library versions on the legacy branch. CI MUST build all board targets
(`BOARD_REV1_DEVKIT`, `BOARD_REV2`) green from a clean checkout. A build that works
only on a developer machine does not exist; `idf.py build` in the pinned container
is the canonical build. Version bumps of toolchain or dependencies are deliberate,
reviewed changes — never floating ranges.

### IV. Frozen Legacy

The Arduino firmware (`src/`, `include/`, `data/`, `test/`, `platformio.ini`) runs
the production greenhouse unit and MUST NEVER be modified on `main` or on feature
branches. Legacy patches go exclusively through the `arduino-maintenance` branch
(via `git worktree`), are built by CI with pinned dependencies, and are tagged
`arduino-v2.3.x`. The `arduino-maintenance` branch is never merged into `main`;
the `arduino-final` tag is the permanent buildable reference.

### V. Checkpoint-Gated AI Workflow

Development is spec-kit driven: each PR derives from `docs/prd/PR-NN-*.md` and gets
`specs/NNN-*/` artifacts (spec, plan, tasks). Human checkpoints are mandatory stops:
CHECKPOINT 2 (plan approval before implementation) and CHECKPOINT 3 (review approval
before commit/PR) MUST NOT be auto-proceeded; CHECKPOINT 1 (clarify) stops only when
open questions exist. Code review (`pr-review-toolkit`) is never skipped. The
orchestrating session never writes implementation code directly — implementation is
delegated to subagents, which inherit the session model (`model: inherit`).
Merge commits always; squash merges are forbidden (they break spec-kit branch
chaining). One branch at a time; `git worktree` for true parallelism.

### VI. English Outward

Everything outward-facing is written in English: code, comments, commit messages,
PR titles and descriptions, issues, and documentation — this is a public repository.
This deliberately overrides any user-global Swedish-language conventions. Dialogue
with Paul (the project owner) remains in Swedish.

## Additional Constraints

- Target hardware: ESP32-WROOM-32E (4 MB flash); partition layout per
  `docs/partition-plan.md` (A/B OTA + NVS + littlefs) — changes to the partition
  table require an explicit migration plan.
- Language level: modern C++ on native ESP-IDF APIs; no Arduino compatibility
  layers in `firmware/`; `std::string` instead of Arduino `String`; RAII; include
  guards in the form `WATERINGSYSTEM_PATH_FILE_H`.
- Logging via `ESP_LOG*` with per-component tags; safety-relevant events (pump
  start/stop, failures, OTA) MUST be persisted.
- Board differences are expressed through the Kconfig board choice
  (`CONFIG_BOARD_REV1_DEVKIT` / `CONFIG_BOARD_REV2`) and the `board` component —
  never through scattered `#ifdef`s in application logic.
- License: AGPL-3.0-or-later. No secrets in the repository; configuration and
  credentials live in NVS on the device.

## Development Workflow

- Pipeline per PR: researcher (optional) → `speckit.specify` → `speckit.clarify`
  → CP1 → `speckit.plan` → `speckit.tasks` → `speckit.analyze` → CP2 →
  `speckit.implement` (via implementer subagent) → `pr-review-toolkit:review-pr`
  → CP3 → fixer (if findings) → verification re-review → commit/PR.
- Every implementation delivers a test checklist: host-test PRs are verified by CI;
  hardware-near PRs ship a HIL checklist that Paul executes on the bench rig at
  CHECKPOINT 3.
- `main` is protected: all changes via feature branch + PR with green CI.
- If review reveals the need for architectural change, return to `speckit.plan`
  rather than patching forward.

## Governance

This constitution supersedes all other practices in this repository, including
user-global instructions where they conflict (see Principle VI). Amendments are
made by PR that updates this file, must include a version bump per semantic
versioning (MAJOR: principle removal/redefinition; MINOR: new principle or
materially expanded guidance; PATCH: clarification), and require Paul's approval.
Every CHECKPOINT 2 plan review and CHECKPOINT 3 code review MUST verify compliance
with these principles; deviations require explicit, documented justification in the
plan's Complexity Tracking section. Runtime development guidance lives in
`CLAUDE.md` (root) and `firmware/CLAUDE.md`.

**Version**: 1.0.0 | **Ratified**: 2026-06-10 | **Last Amended**: 2026-06-10

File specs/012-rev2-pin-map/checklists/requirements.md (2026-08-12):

# Specification Quality Checklist: rev2 board profile aligned with frozen hardware

**Purpose**: Validate specification completeness and quality before proceeding to planning
**Created**: 2026-08-12
**Feature**: [spec.md](../spec.md)

## Content Quality

- [x] No implementation details (languages, frameworks, APIs)
- [x] Focused on user value and business needs
- [x] Written for non-technical stakeholders
- [x] All mandatory sections completed

## Requirement Completeness

- [x] No [NEEDS CLARIFICATION] markers remain
- [x] Requirements are testable and unambiguous
- [x] Success criteria are measurable
- [x] Success criteria are technology-agnostic (no implementation details)
- [x] All acceptance scenarios are defined
- [x] Edge cases are identified
- [x] Scope is clearly bounded
- [x] Dependencies and assumptions identified
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

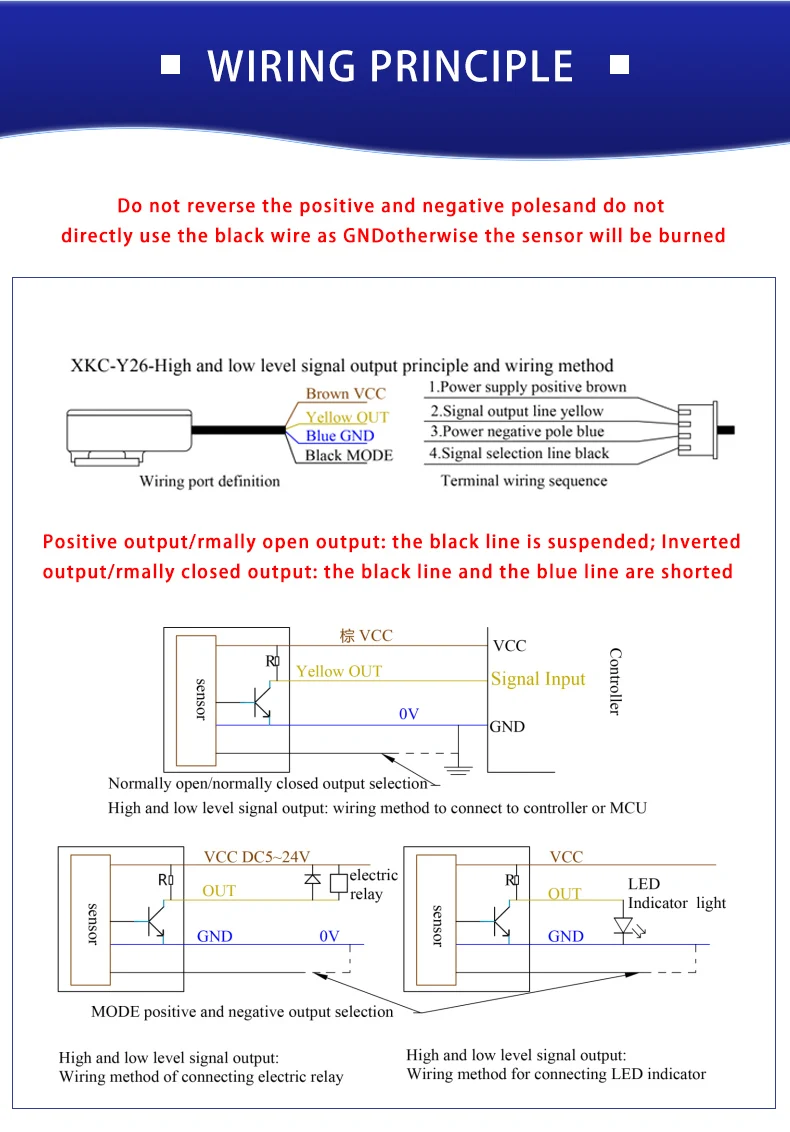
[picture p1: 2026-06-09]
XKC-Y26-connection-scheme.webp

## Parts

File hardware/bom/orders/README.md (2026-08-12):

# Parts orders

One file per order, named `YYYY-MM-DD-<vendor>-order.csv`. These are records of
what was actually ordered, generated from the master BOM
(`../WateringSystem-rev2-BOM.md`) — never hand-maintained.

## 2026-08-12 — LCSC, module prototype stage

Generated from the master BOM for the stage-A module boards
(`../../rev2/design-notes/09-prototype-modules.md`). **51 line items,
~2300 components.**

### Upload

LCSC's **BOM Tool** (lcsc.com → *BOM Tool* / *Quick Order*) takes a CSV or
Excel upload and turns it into a cart. Upload `2026-08-12-lcsc-order.csv`,
then map the columns when prompted — the file uses LCSC's own header names,
so the mapping is usually detected automatically:

| Column | Purpose |
|---|---|
| `LCSC Part Number` | The one column that actually matters (C-numbers) |
| `Quantity` | Desired count — see the policy below |
| `Manufacturer Part Number` | Cross-check that LCSC resolves the same part |
| `Designator`, `Description` | Human context; LCSC ignores them |

**LCSC rounds quantities up to each part's MOQ / packaging multiple** and shows
the adjustment before checkout — so the numbers below are intent, not the exact
invoice. Review that screen rather than pre-computing MOQs.

### Quantity policy

Enough for **two complete board sets** (one to build, one to redo after a
hot-plate mistake), with deliberate over-ordering where a part is cheap and
losing one costs a re-order:

| Class | Ordered | Why |
|---|---|---|
| 0402/0603 R and C (pF/nF/0.1 µF/1 µF) | 100 | Cents each; hand-assembly attrition is real (tweezer launches, reflow drift) |
| Bulk ceramics (4.7/10/22 µF) | 20 | Bigger, pricier, less likely to vanish |
| Electrolytics, inductor, shunts | 5 | Few per board, distinctive |
| Discrete semis (MOSFET, TVS, zener, Schottky, ESD) | 5 | Cheap, easy to cook |
| Connectors, switches | 5 | THT/SMD mechanical, survives rework |
| ICs (ESP32, CP2102N, MP2393, THVD1426, BME280) | 2 | One spare each — the parts most likely to be killed by a bad reflow |
| INA226 | 4 | Two per board (0x40 pump + 0x41 solar) × 2 sets |
| LED | 10 | Trivial cost |

### NOT in this order — source elsewhere

| Item | Where | Note |
|---|---|---|
| Weidmüller 1715010000 ×4 (J2, J3, J8, J9) | **Already in Paul's stock** | Off-LCSC; chosen precisely because they were on hand |
| 2.54 mm pin headers + female sockets (J100/J101 module interconnect, J6, J7) | **Already in Paul's stock** | Assorted female-header kit + breakable male strips. Deliberately no C-number here: the old BOM's `C2337` for J6 was status *Partial* (unverified) and is not worth trusting |
| Solder paste, flux, braid, 0.1 mm stencil | JLCPCB (stencil) / local | See `../../rev2/HOWTO-module-pcb.md` §9 |
| 10 A blade fuse + waterproof inline holder | Jula, at install | `../../rev2/design-notes/01-power.md` §1.1 — SAFETY-REQUIRED |

### Verified before generating

- Built from `WateringSystem-rev2-BOM.md` only — the CSV/LCSC exports that sat
  beside it in `hardware/bom/` were byte-identical copies of the archived
  pre-restructure generation (MP2307, 22 µH inductor, 2 mΩ shunts, F1 polyfuse,
  R4/R5 bias) and would have produced a wrong order. They have been removed;
  `archive/` still holds them.
- Solar telemetry group **included** (U20 C49851, R27 C553969, C29 C14663) per
  the cleared gate — see `01-power.md` §1.5.
- Current generation confirmed: U4 = C6674609 (MP2393), L20 = C5189747
  (3.3 µH, 9.5 A sat), R1 = C5375417 (5 mΩ), U1 = C701344 (WROOM-32UE-N4).

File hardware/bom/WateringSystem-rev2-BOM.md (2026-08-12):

# WateringSystem rev2 — Master BOM

**The procurement roll-up for the rev2 node.** Built **incrementally**, one
block at a time, from the per-block design-notes. A block's rows appear here only
once its design-note (`hardware/rev2/design-notes/0N-*.md`) has been worked — so
a missing block means *"not started yet"*, not *"forgotten"*. See the coverage
table below.

> ⚠️ **WORK IN PROGRESS — all 8 blocks drafted (2026-06-24), not yet order-ready.**
> Both open design decisions are now closed (2026-06-24): level-sensor supply =
> switched `SENS_12V` (`06` §6.2); expansion J7 = populated, generic VSPI breakout
> (`08` §8.4). Remaining before fabrication: (1) confirm the `cand`/`—` LCSC numbers
> + connector models in the Fabrication Toolkit plugin; (2) per-sheet + root-level
> ERC. Cost summary / purchasing strategy
> stay in the archived reference (`archive/WateringSystem-rev2-BOM.md`) until the
> `cand` parts are confirmed, so no half-finished total can mislead.

## Single source of truth — who owns what

| Fact | Lives in | Notes |
|---|---|---|
| refdes, value, package, MPN, role, connectivity, net names | **design-note** `0N-*.md` | the *design* truth |
| LCSC#, LCSC status, JLC type, alternatives | **this file** | the *procurement* truth |

Flow is one-way: design → procurement. Change an MPN in the design-note, this
file follows. The volatile vendor data (C-number, stock, Basic/Extended) has
exactly one home: here.

## Coverage / block status

| # | Block | Design-note | BOM status |
|---|---|---|---|
| 1 | Power | `01-power.md` | ✅ **in this file** |
| 2 | MCU (ESP32) | `02-mcu.md` | ✅ **in this file** |
| 3 | USB-UART (CP2102N) | `03-usb-uart.md` | ✅ **in this file** |
| 4 | RS485 / sensor | `04-rs485.md` | ✅ **in this file** |
| 5 | Pump driver + INA226 | `05-pump.md` | ✅ **in this file** |
| 6 | Level sensors | `06-level-sensors.md` | ✅ **in this file** |
| 7 | I²C / environment (BME280) | `07-i2c-env.md` | ✅ **in this file** |
| 8 | Expansion header | `08-expansion.md` | ✅ **in this file** |

## How to read the LCSC columns

**Workflow:** for each row, read `LCSC#` → pull symbol/footprint/3D into KiCad
via the Fabrication Toolkit plugin → confirm the part. Resolve `choice`/`—` rows
with Paul in chat, then the C-number is written back here.

- **St** (LCSC status):
  - `✓` — verified (confirmed in plugin, or carried from the archive's verified pass)
  - `cand` — candidate from an LCSC web-search hit, **unconfirmed** — confirm in plugin
  - `choice` — several valid options exist; **your pick** (see Alternatives)
  - `—` — not found / generic passive you'll pick as a Basic part in the plugin
- **JLC** — JLCPCB type: `BP` Basic (no setup cost) · `EP` Extended (~$3 setup) · `?` unconfirmed · `—` n/a
- **Alternatives** — up to 3 other LCSC listings for the same part (clones / second sources). Empty = none worth listing.

`LCSC#` is the primary suggestion; `Alternatives` are the runners-up.

## External / off-board materiel (per node)

Not on the PCB, but part of every node build. Decisions tracked here so the
procurement picture is complete.

| Item | Chosen / candidate | Status | Notes |
|---|---|---|---|
| Charge controller | **Renogy Voyager RCC10VOYP** (PWM 10 A, IP67, Li profile) | ✅ chosen 2026-08-10 | **Common-POSITIVE** → J9 pin 1 n.c. (`01-power.md` §1.5). Battery type must be set to **LI manually** at install (auto-recognition = non-lithium only). Self-consumption 0.22 W ≈ 5 Wh/day — in energy budget, margin OK |
| Battery | 12.8 V 7.2 Ah LiFePO4 w/ built-in BMS (e.g. V-TAC) | candidate | ≈ 9 days autonomy without sun (always-on profile) |
| Solar panel | Rigid 20 W mono, glass + aluminium frame | candidate | ≈ 80–100 Wh/day in season; PWM harvest loss acceptable at this margin. Avoid flexible AliExpress panels |
| Fuse | Inline blade-fuse holder + 5 A fuse, battery + lead | required | As close to the battery as practical (`01-power.md` §1.1) |
| Antenna | SMA bulkhead + U.FL pigtail (WROOM-32UE) | per node | Mounted on the IP66/68 enclosure |

---

# Block 1 — Power

Design-note: `hardware/rev2/design-notes/01-power.md` (connectivity, net names,
buck calculations, `[VERIFY]` items). Roles below are abbreviated — the note is
authoritative.

## Main group (always populated)

| Ref | Qty | Value / part | Package | MPN | LCSC# | St | JLC | Alternatives (≤3) | Role |
|---|---|---|---|---|---|---|---|---|---|
| J2 | 1 | Terminal block 2-pin 5.08 mm | THT | Weidmüller 1715010000 | — | — | — | — | Battery input — model chosen; THT, off-LCSC (source via Weidmüller/Mouser) |
| Q20 | 1 | P-MOSFET −40 V, ≤10 mΩ | TO-252 (DPAK) | AOD4185 (AOS) | C400894 | ✓ | EP | C5261064 (HXY clone), C879147 (VBsemi clone) | Reverse-polarity protection (ideal diode) — genuine AOS chosen |
| Q21 | 1 | P-MOSFET −30 V | SOT-23 | AO3401A | C15127 | ✓ | BP | — | High-side switch, sensor 12 V rail |
| D20 | 1 | TVS unidir, 15 V standoff, 600 W | SMB (DO-214AA) | SMBJ15A/TR13 (Brightking) | C78409 | ✓ | EP | C135046 (Diodes), C283618 (ST) | Input transient clamp |
| D21 | 1 | Zener 10 V, 500 mW | SOD-123 | BZT52C10 | C216719 | cand | EP | C5244686 (Diodes), C511887 (BORN) | Q20 gate clamp — unified to 10 V to share with D22 |
| D22 | 1 | Zener 10 V, 500 mW | SOD-123 | BZT52C10 | C216719 | cand | EP | C5244686 (Diodes) | **Q21 gate clamp** (review A2; Vgs ≤ AO3401A ±12 V) — **same part as D21** |
| U4 | 1 | Buck 3 A COT, 4.2–24 V in, PG+SS | SOT583 | MP2393GTL-Z | C6674609 | ✓ | EP | — | 12 V → 3.3 V (replaces NRND MP2307) |
| L20 | 1 | Power inductor 3.3 µH, ≥4 A sat, shielded | SMD 6×6 | CYA0630-3.3UH (SHOU HAN) | C5189747 | ✓ | EP | — | Buck inductor — sat verified 9.5 A DC per datasheet (2026-08-12) ✓ |
| C20 | 1 | Electrolytic 100 µF, 25 V | SMD radial 6.3×7.7 | RVT1E101M0607 (ROQANG) | C72477 | ✓ | EP | C179802 (SUNCON), C970685 (DMBJ) | Input bulk |
| C21 | 1 | Ceramic X7R 10 µF, ≥25 V | 1206 | CL31B106KBHNNNE (50V) | C89632 | ✓ | EP | — | Input HF decoupling (50 V ≥ 25 V OK) |
| C22 | 1 | Ceramic X7R 10 µF, ≥25 V | 1206 | CL31B106KBHNNNE (50V) | C89632 | ✓ | EP | — | Buck IN decoupling |
| C32 | 1 | Ceramic 0.1 µF, 50 V X7R | 0603 | CC0603KRX7R9BB104 | C14663 | ✓ | BP | — | Input HF at IN (datasheet C1A) |
| C23 | 1 | Ceramic 1 µF, 50 V X5R | 0603 | CL10A105KB8NNNC (Samsung) | C15849 | ✓ | BP | — | Bootstrap cap (BST–SW); X5R fine here |
| R29 | 1 | 20 Ω 1% | 0603 | 0603WAF200JT5E (Uniroyal) | C22950 | ✓ | BP | — | Bootstrap series resistor (SW–BST) |
| C24, C25 | 2 | Ceramic 22 µF, 25 V X5R | 1206 | CL31A226KAHNNNE (Samsung) | C12891 | ✓ | BP | C49326822 (22µF 1210 X7R 63V), C87996 (22µF 10V X7R 1206) | 3V3 output — X5R chosen (OK at 3.3 V) |
| R21 | 1 | 40.2 kΩ 1% | 0603 | RC0603FR-0740K2L (Yageo) | C137723 | ✓ | EP | — | FB divider top |
| R22 | 1 | 13 kΩ 1% | 0603 | 0603WAF1302T5E (Uniroyal) | C22797 | ✓ | BP | — | FB divider bottom (V_out 3.29 V) |
| R28 | 1 | 20 kΩ 1% | 0603 | 0603WAF2002T5E (Uniroyal) | C4184 | ✓ | BP | — | RT — series into FB (COT ripple injection) |
| C30 | 1 | 10 pF C0G, 50 V | 0603 | CL10C100JB8NNNC (Samsung) | C1634 | ✓ | BP | — | Feedforward across R21 |
| C27 | 1 | Ceramic 6.8 nF, 50 V X7R | 0603 | 0603B682K500NT (FH) | C1631 | ✓ | BP | — | Soft-start (SS, ~1.5 ms) — C-number confirmed (2026-08-12) ✓ |
| R24 | 1 | 1 MΩ 1% | 0603 | 0603WAF1004T5E (Uniroyal) | C22935 | ✓ | BP | — | EN pullup → VBAT (datasheet 604k; 1 MΩ → 11 µA, safe) |
| C31 | 1 | Ceramic 1 nF, 50 V X7R | 0603 | CL10B102KB8NNNC (Samsung) | C1588 | ✓ | BP | — | PG decoupling |
| R30 | 1 | 100 kΩ 1% | 0603 | 0603WAF1003T5E (Uniroyal) | C25803 | ✓ | BP | — | PG pullup → 3V3 |
| R31 | 1 | 1 kΩ 1% | 0603 | 0603WAF1001T5E (Uniroyal) | C21190 | ✓ | BP | — | Q21 gate series (review A2; limits D22 clamp current) |
| C28 | 1 | Ceramic 100 nF, 50 V X7R | 0603 | CC0603KRX7R9BB104 | C14663 | ✓ | BP | — | ADC filter, battery sense |
| R20 | 1 | 100 kΩ 1% | 0603 | 0603WAF1003T5E (Uniroyal) | C25803 | ✓ | BP | — | Q20 gate pulldown |
| R25 | 1 | 470 kΩ 1% | 0603 | 0603WAF4703T5E (Uniroyal) | C23178 | ✓ | BP | — | Battery sense, top |
| R26 | 1 | 100 kΩ 1% | 0603 | 0603WAF1003T5E (Uniroyal) | C25803 | ✓ | BP | — | Battery sense, bottom |

**Buck-IC change 2026-06-21:** MP2307 (NRND) → **MP2393GTL-Z** (active, COT, FB-ref
0.805 V). Removed vs MP2307: **R23** (6.8 kΩ COMP) and **C26** (3.9 nF COMP) — COT
needs no external compensation. Added: R28 (RT), R29 (BST resistor), R30 (PG
pullup), C30 (feedforward), C31 (PG cap), C32 (input HF). New signal **`PWR_PG`**
(PG → MCU GPIO). See `01-power.md` §1.2.

## Optional group — solar telemetry (on board; populate per node)

**Decision 2026-06-20: the design includes the solar section** — J8/J9, U20, R27,
C29 footprints are on every board. Whether they are *placed* at assembly is a
per-node BOM toggle, so it can be dropped later at no PCB cost.
~~**Gate before populating:** confirm a common-negative charge controller;
on a common-positive controller leave U20/R27 unpopulated.~~
**GATE CLEARED 2026-08-10 — this node POPULATES the solar group.** The chosen
Renogy Voyager RCC10VOYP is **common-positive**, but the analysis in
`01-power.md` §1.5 showed the telemetry loop works regardless: the shunt sits in
the panel **+** lead, so its common-mode potential is battery voltage — well
inside the INA226's 36 V range. The old gate assumed a common-negative
controller was *required*; it is not. The one real constraint is wiring:
**J9 must never be tied to board GND** (it is the isolated `PANEL_RTN`
pass-through, §1.5.1). Populate U20, R27, C29, J8, J9 on this node.

| Ref | Qty | Value / part | Package | MPN | LCSC# | St | JLC | Alternatives (≤3) | Role |
|---|---|---|---|---|---|---|---|---|---|
| J8, J9 | 2 | Terminal block 2-pin 5.08 mm (2× ganged = 4 pos) | THT | Weidmüller 1715010000 | — | — | — | — | Panel pass-through — **off-LCSC, already in Paul's stock** (same part as J2/J3); gang two 2-pole at 5.08 mm pitch: J8 = `PANEL_IN`/`PANEL_OUT`, J9 = `PANEL_RTN` in/out (isolated, never GND) |
| U20 | 1 | INA226, addr 0x41 | VSSOP-10 (MSOP-10) | INA226AIDGSR | C49851 | ✓ | EP | — | Panel telemetry |
| R27 | 1 | Shunt 20 mΩ 1 W 1% | 2512 | WSL2512R0200FEA (Vishay) | C553969 | ✓ | EP | — | Panel current shunt — populated (Isc 3.17 A → 63 mV, §1.5) |
| C29 | 1 | Ceramic 100 nF, 50 V X7R | 0603 | CC0603KRX7R9BB104 | C14663 | ✓ | BP | — | U20 decoupling |

## Open procurement / design items for block 1

1. **L20 = 3.3 µH — RESOLVED 2026-06-24** (review C2). The old "10 µH" was the
   MP2307-era value (~340 kHz). The **MP2393 runs 650 kHz**, so the standard
   selection L = Vout·(Vin−Vout)/(Vin·f·ΔIL) at 12 V→3.3 V, 650 kHz, ΔIL≈1 A gives
   **≈3.1–3.7 µH → 3.3 µH** (CYA0630-3.3UH, `C5189747`, ≥4 A sat). The frequency jump
   is exactly why the inductor shrank from 10 µH. The stale 10 µH text is removed.
2. **D20 polarity — resolved.** D20 = SMBJ15A/TR13 (Brightking) `C78409`,
   **unidirectional** (was bidirectional SMBJ15CA `C78809` in the archive).
   Correct for a DC rail clamp that never goes negative behind the
   reverse-protection FET.
3. **Genuine vs clone — chosen** (pulled into KiCad): Q20 = genuine AOS `C400894`,
   D20 = Brightking `C78409`. D21/D22 = BZT52C10 `C216719` (cand — confirm in
   plugin; the earlier 12 V/`C2104` pick was superseded by the 10 V unification,
   2026-06-24). The `Alternatives` column keeps the runner-ups as fallback.
4. ~~COMP/FB values (MP2307-era)~~ — **superseded 2026-06-21** by the MP2393
   redesign: R23/C26 (COMP) removed, divider = R21 40.2 k / R22 13 k (§1.2).
   Entry kept for history only — do not order these values.
5. ~~C26 / C24·C25 picks (MP2307-era)~~ — **superseded:** C26 no longer exists
   (COT, no COMP); C24/C25 = `C12891` per the table above. History only.

## Refdes note

This block uses the `01-power.md` numbering (`Q20/Q21`, `D20/D21`, `R20–R30`,
`C20–C32`, `L20`, `U4` buck, `U20` solar). The archived BOM used a different
scheme (`Q3`, `D3`, `C1/C5`, `L1`, `F1`) — ignore it; the design-note is the
source of truth and KiCad re-annotates anyway.

---

# Block 2 — MCU (ESP32-WROOM-32UE)

Design-note: `hardware/rev2/design-notes/02-mcu.md` (pin-type table, SYNC 1 GPIO
map, pin-by-pin connectivity). New parts use the 40-series; passives mostly reuse
block-1 / archive C-numbers.

| Ref | Qty | Value / part | Package | MPN | LCSC# | St | JLC | Alternatives (≤3) | Role |
|---|---|---|---|---|---|---|---|---|---|
| U1 | 1 | ESP32-WROOM-32UE-N4 (4 MB, U.FL) | Module | ESP32-WROOM-32UE-N4 | C701344 | ✓ | EP | C701341 (−32E PCB-ant) | MCU |
| C40 | 1 | Ceramic 10 µF, 25 V X5R | 0805 | CL21A106KAYNNNE (Samsung) | C15850 | ✓ | BP | — | Module bulk decoupling |
| C41 | 1 | Ceramic 100 nF, 50 V X7R | 0603 | CC0603KRX7R9BB104 | C14663 | ✓ | BP | — | Module HF decoupling (3V3 pin) |
| C42 | 1 | Ceramic 1 µF, 50 V X5R | 0603 | CL10A105KB8NNNC (Samsung) | C15849 | ✓ | BP | — | EN power-on-reset RC — 1 µF for auto-reset (block 3 §3.3.5); X5R OK (POR, X7R 1µF is Extended-only) |
| C43 | 1 | Ceramic 1 nF, 50 V X7R | 0603 | CL10B102KB8NNNC (Samsung) | C1588 | ✓ | BP | — | IO0 noise filter (optional) |
| R11 | 1 | 10 kΩ 1% | 0603 | 0603WAF1002T5E (Uniroyal) | C25804 | ✓ | BP | — | EN pullup → +3V3 |
| R12 | 1 | 10 kΩ 1% | 0603 | 0603WAF1002T5E (Uniroyal) | C25804 | ✓ | BP | — | IO0 pullup → +3V3 |
| R40 | 1 | 1 kΩ 1% | 0603 | 0603WAF1001T5E (Uniroyal) | C21190 | ✓ | BP | — | Status-LED series |
| LED2 | 1 | LED bright green | 0805 | 150080VS75000 (Wurth) | C5148523 | ✓ | EP | — | Status LED (IO2) |
| SW1 | 1 | Tactile switch | SMD 5.1×5.1 | TS-1187A-B-A-B (XKB) | C318884 | ✓ | BP | — | BOOT (IO0 → GND) |
| SW2 | 1 | Tactile switch | SMD 5.1×5.1 | TS-1187A-B-A-B (XKB) | C318884 | ✓ | BP | — | RESET (EN → GND) |
| J6 | 1 | Pin header 1×6 (DNP) | 2.54 mm THT | generic (Conn_01x06) | — | — | — | — | JTAG breakout — KiCad generic, no LCSC import; DNP (TMS/TCK/TDI/TDO/GND/+3V3 — pin 6 = +3V3 Vtarget sense, resolved 2026-06-23) |

**Notes:** C41/C42/C43 reuse block-1 ceramics; R11/R12 (10 kΩ) = C25804, R40
(1 kΩ) = C21190 (archive-verified). U1 = −32UE (U.FL ext-antenna) with −32E
(C701341, PCB antenna) as the populate-time alternative — **same footprint**.
LED2/SW1/SW2 confirmed in the plugin (✓, 2026-06/07).
J6 is DNP (debug insurance) — pick a header model in the plugin if/when populating.

---

# Block 3 — USB-UART programming bridge (CP2102N)

Design-note: `hardware/rev2/design-notes/03-usb-uart.md` (CP2102N pin-type table,
bus-powered island topology, USB-C device wiring, the cross-coupled two-transistor
auto-program circuit). New parts use the 50-series. Bus-powered bridge — its 3.3 V
(`VDD_USB`) is a separate island, **not** the board `+3V3`.

| Ref | Qty | Value / part | Package | MPN | LCSC# | St | JLC | Alternatives (≤3) | Role |
|---|---|---|---|---|---|---|---|---|---|
| U2 | 1 | CP2102N USB-UART bridge | QFN-24 (4×4 EP) | CP2102N-A02-GQFN24R | C969151 | ✓ | EP | — | USB-to-UART — A02 silicon; **on hand (Paul)**; separate VIO pin (tie pin 5→6) |
| J1 | 1 | USB-C receptacle, 16-pin, USB-2.0 | SMD | TYPE-C-31-M-12 (Korean Hroparts) | C165948 | ✓ | EP | — | Host connector — bare USB-2.0 (no internal CC resistors) |
| D50 | 1 | USB ESD array, 2-line | SOT-23-6 | USBLC6-2SC6 (ST) | C7519 | ✓ | EP | — | D+/D− ESD + VBUS clamp — verify SOT-23-6 pinout at place |
| Q50 | 1 | NPN transistor | SOT-23 | MMBT3904 | C20526 | ✓ | BP | C2146 (S8050), C2150 (SS8050) | Auto-reset: pulls `EN` low (emitter → RTS) |
| Q51 | 1 | NPN transistor | SOT-23 | MMBT3904 | C20526 | ✓ | BP | C2146 (S8050), C2150 (SS8050) | Auto-reset: pulls `BOOT` low (emitter → DTR) |
| R50 | 1 | 10 kΩ 1% | 0603 | 0603WAF1002T5E (Uniroyal) | C25804 | ✓ | BP | — | Q50 base series (from DTR) |
| R51 | 1 | 10 kΩ 1% | 0603 | 0603WAF1002T5E (Uniroyal) | C25804 | ✓ | BP | — | Q51 base series (from RTS) |
| R52 | 1 | 5.1 kΩ 1% | 0603 | 0603WAF5101T5E (Uniroyal) | C23186 | ✓ | BP | — | USB-C CC1 pulldown (Rd, sink) |
| R53 | 1 | 5.1 kΩ 1% | 0603 | 0603WAF5101T5E (Uniroyal) | C23186 | ✓ | BP | — | USB-C CC2 pulldown (Rd, sink) |
| R54 | 1 | 22 kΩ 1% | 0603 | 0603WAF2202T5E (Uniroyal) | C31850 | ✓ | BP | — | VBUS sense divider, top (E24 Basic; →3.41 V) — C# Paul-confirmed |
| R55 | 1 | 47 kΩ 1% | 0603 | 0603WAF4702T5E (Uniroyal) | C25819 | ✓ | BP | — | VBUS sense divider, bottom (E24 Basic) — C# verified 0603 |
| R56 | 1 | 470 Ω 1% | 0603 | 0603WAF4700T5E (Uniroyal) | C23179 | ✓ | BP | — | `U0TXD` series — island back-power isolation (review A3, 2026-07-02); C# Paul-confirmed |
| R57 | 1 | 470 Ω 1% | 0603 | 0603WAF4700T5E (Uniroyal) | C23179 | ✓ | BP | — | `U0RXD` series — island back-power isolation; same part as R56 |
| C50 | 1 | Ceramic 1 µF, 50 V X5R | 0603 | CL10A105KB8NNNC (Samsung) | C15849 | ✓ | BP | — | VREGIN bulk (reuse block-1 1 µF) |
| C51 | 1 | Ceramic 100 nF, 50 V X7R | 0603 | CC0603KRX7R9BB104 | C14663 | ✓ | BP | — | VREGIN HF |
| C52 | 1 | Ceramic 4.7 µF, 16 V X5R | 0603 | CL10A475KO8NNNC (Samsung) | C19666 | ✓ | BP | — | VDD (LDO output) decoupling — X5R Basic 0603 (Paul-confirmed) |
| C53 | 1 | Ceramic 100 nF, 50 V X7R | 0603 | CC0603KRX7R9BB104 | C14663 | ✓ | BP | — | VDD HF |

**Notes:** U2 = **CP2102N-A02-GQFN24R (`C969151`)** — the part Paul has on hand (QFN-24,
separate VIO pin → tie pin 5→6); if hand-placed (hotplate), its JLC class is moot.
J1/D50 are **Extended** (no Basic USB-C / ESD array at JLC) — accept the feeder fee. Q50/Q51 use **MMBT3904 (C20526,
Basic)** to keep the transistor pair off the Extended list; S8050/SS8050 are Basic
alternatives. Passives mostly reuse block-1 C-numbers; 22 k/47 k are E24 Basic
(swapped from E96 22.1k/47.5k, same 3.41 V divider); C52 + R52/R53 confirmed ✓.
**R56/R57 (470 Ω UART series — island back-power isolation, second-opinion review A3
2026-07-02): 0603WAF4700T5E `C23179` (Basic, Paul-confirmed 2026-07-02).**

**Auto-reset note:** Q50/Q51 emitters cross-couple to the *opposite* control line
(Q50 emitter → RTS, Q51 emitter → DTR), **not** to GND — see `03-usb-uart.md` §3.3.5.
The EN/BOOT pull-ups + RC live in block 2; this block only pulls them low. Reliable
auto-reset wants block-2 `C42` = **1 µF** (recommended in `03-usb-uart.md` §3.4).

---

# Block 4 — RS485 / sensor interface (THVD1426)

Design-note: `hardware/rev2/design-notes/04-rs485.md` (THVD1426 pin-type table,
resolved bias/RE̅/SHDN̅ decisions, pin-by-pin connectivity, sensor-rail gate driver).
New parts use the 60-series. **External A/B bias (old R4/R5) removed** — the
THVD1426 internal receiver fail-safe makes it unnecessary (§4.2).

| Ref | Qty | Value / part | Package | MPN | LCSC# | St | JLC | Alternatives (≤3) | Role |
|---|---|---|---|---|---|---|---|---|---|
| U3 | 1 | RS485 auto-direction, ±12 kV IEC | SOT-8 (5×3) | THVD1426DRLR (TI) | C5215922 | ✓ | EP | — | Transceiver — only variant stocked at both LCSC + Mouser; not SOIC-8 |
| C60 | 1 | Ceramic 100 nF, 50 V X7R | 0603 | CC0603KRX7R9BB104 | C14663 | ✓ | BP | — | U3 VCC decoupling |
| R3 | 1 | 120 Ω 1% | 0603 | 0603WAF1200T5E (Uniroyal) | C22787 | ✓ | BP | — | Bus termination (single-end; DNP if sensor embeds one) |
| D4 | 1 | RS485 TVS, asymmetric +12/−7 V | SOT-23 | SM712.TCT (Semtech) | C12067 | ✓ | EP | SMAJ12CA-pair | A/B surge/EFT — restored from archive verified pass (review B1) |
| J4 | 1 | Connector 4-pin (A/B/SENS_12V/GND) | THT | JST-XH4 | C144395 | — | — | — | Sensor/Modbus field connector — pick model in plugin (JST-XH or terminal) |
| Q60 | 1 | N-MOSFET 60 V | SOT-23 | 2N7002 | C8545 | ✓ | BP | — | Sensor-rail gate driver (pulls SENS_GATE low) |
| R60 | 1 | 100 kΩ 1% | 0603 | 0603WAF1003T5E (Uniroyal) | C25803 | ✓ | BP | — | Q60 gate pulldown → GND (default-off safety) |
| R61 | 1 | 100 kΩ 1% | 0603 | 0603WAF1003T5E (Uniroyal) | C25803 | ✓ | BP | — | SENS_GATE pullup → VBAT (holds Q21 off) |

**Notes:** U3 = THVD1426**DRLR** (SOT-8 5×3) — the variant available at both LCSC
(C5215922) and Mouser; **not** THVD1426DR (SOIC-8), and don't confuse with
THVD1452DR (C1850237, a different full-duplex device). **R4/R5 (old 680 Ω bias)
removed** — internal fail-safe. D4 = SM712.TCT `C12067` (✓ archive-verified,
restored review B1). Q60 = 2N7002 `C8545` (✓) — same line item as block-6 Q1.
R3 120 Ω + J4: pick Basic / connector model in the plugin.

---

# Block 5 — Pump driver + current sense (INA226)

Design-note: `hardware/rev2/design-notes/05-pump.md` (INA226 pin-type table,
low-side FET switch + flyback/TVS, high-side shunt, pin-by-pin connectivity).
Adapted from the archived two-pump design to **single pump**. New part = C70.
LCSC numbers carried from the archive's verified pass (`hardware/bom/archive/`).

| Ref | Qty | Value / part | Package | MPN | LCSC# | St | JLC | Alternatives (≤3) | Role |
|---|---|---|---|---|---|---|---|---|---|
| Q2 | 1 | N-MOSFET 40 V 120 A, Vgs(th) ≤2.5 V | DPAK (TO-252) | NCE40H12K | C148243 | ✓ | EP | DMTH4004LK3 (C260930), AOD4184A (C99124) | Low-side pump switch — low-threshold for direct 3.3 V gate (§5.3; bench-confirm) |
| D1 | 1 | Schottky 40 V 10 A | TO-277A (SMPC) | SS10P4-M3/86A (Vishay) | C968538 | ✓ | EP | — (no Basic 10 A exists; EP accepted) | Flyback across pump — 10 A headroom for FL-35; K = tab, A = pins 1+2 (§5.3-1) |
| D2 | 1 | TVS bidirectional, 16 V standoff | SMB | SMBJ16CA (Littelfuse) | C151255 | ✓ | EP | — | Q2 drain–source clamp |
| R1 | 1 | Current shunt 5 mΩ 1% ≥2 W | 2512 | HoYLR2512-2W-5mR-1% (Milliohm) | C5375417 | ✓ | EP | HoJLR2512-3W-5mR-1% (C2903482, 3 W) | High-side pump shunt — 5 mΩ → INA226 FS ≈ 16 A (FL-35: ~4 A run / 8 A max; P ≤ 0.32 W on 2 W part, §5.3) |
| R8 | 1 | 10 kΩ 1% | 0603 | 0603WAF1002T5E (Uniroyal) | C25804 | ✓ | BP | — | Q2 gate pulldown (pump OFF at boot — safety) |
| R9 | 1 | 100 Ω 1% | 0603 | 0603WAF1000T5E (Uniroyal) | C22775 | ✓ | BP | — | Q2 gate series |
| C5 | 1 | Electrolytic 470 µF 25 V | SMD | UWT1E471MNL1GS (Nichicon) | C507622 | ✓ | EP | — | Pump-start bulk (VBAT) — confirm LCSC/footprint in plugin |
| U5 | 1 | INA226, addr 0x40 | MSOP-10 | INA226AIDGSR | C49851 | ✓ | EP | — | Pump current + bus voltage (A0/A1 = GND) |
| C70 | 1 | Ceramic 100 nF, 50 V X7R | 0603 | CC0603KRX7R9BB104 | C14663 | ✓ | BP | — | U5 VS decoupling |
| J3 | 1 | Terminal block 2-pin 5.08 mm | THT | Weidmüller 1715010000 | — | — | — | — | Pump output — off-LCSC, same family as J2 |

**Notes:** U5 = INA226 @ **0x40** (A0/A1→GND) — distinct from block-1 U20 @ 0x41 and
BME280 0x76/0x77. Q2 = **NCE40H12K** (`C148243`, was NCE4060K) — switched to a
**low-threshold** part (Vgs(th) max 2.5 V) so it fully turns on from a 3.3 V GPIO; no
DPAK FET publishes a 2.5 V RDS spec → bench-confirm on the phase-1 rig (`05-pump.md`
§5.3). **Pump confirmed (2026-06-25): Floline / Sunflo FL-35, 12 V, ~4 A running,
~8 A max** → R1 resized 2 mΩ → **5 mΩ** (FS ≈ 16 A). D1 upgraded SS54 → **SS10P4**
(`C968538`, 10 A, TO-277A) for headroom; footprint SMA → TO-277A. NCE40H12K at 4–5 A:
~0.18 W (~7 °C) with copper pour. R9 100 Ω + C5 470 µF: pick Basic / electrolytic
model in the plugin.

---

# Block 6 — Reservoir level sensors (XKC-Y26 + 2N7002 invert)

Design-note: `hardware/rev2/design-notes/06-level-sensors.md` (XKC-Y26 facts, MODE
tie, 2N7002 invert topology, fail-safe, supply decision). **Two identical channels
with explicit refdes** (LOW = Q1/R80/R6/R7/JP1/J5 → IO32; HIGH = Q81/R81/R82/R83/
JP2/J10 → IO33) → qty 2 per line covers both. The XKC-Y26 sensors are **off-board**
(field-wired via J5/J10) — not PCB BOM lines.

| Ref | Qty | Value / part | Package | MPN | LCSC# | St | JLC | Alternatives (≤3) | Role |
|---|---|---|---|---|---|---|---|---|---|
| Q1 *(LOW)*, Q81 *(HIGH)* | 2 | N-MOSFET 60 V | SOT-23 | 2N7002 | C8545 | ✓ | BP | — | Level-shift/invert XKC OUT (12 V) → 3.3 V GPIO |
| R6 *(LOW)*, R82 *(HIGH)* | 2 | 100 kΩ 1% | 0603 | 0603WAF1003T5E (Uniroyal) | C25803 | ✓ | BP | — | Gate pulldown → GND (default-off, disconnected-safe) |
| R7 *(LOW)*, R83 *(HIGH)* | 2 | 10 kΩ 1% | 0603 | 0603WAF1002T5E (Uniroyal) | C25804 | ✓ | BP | — | Drain pullup → +3V3 |
| R80 *(LOW)*, R81 *(HIGH)* | 2 | 10 kΩ 1% | 0603 | 0603WAF1002T5E (Uniroyal) | C25804 | ✓ | BP | — | Gate series (OUT→gate) — field-transient hardening (review D1) |
| JP1 *(LOW)*, JP2 *(HIGH)* | 2 | Solder jumper (MODE↔GND) | — | KiCad SolderJumper | — | — | — | — | MODE polarity — **default OPEN** (floating = active-HIGH, mirrors rev1 JP4); close→GND to invert. No part (review A1) |
| J5 *(LOW)*, J10 *(HIGH)* | 2 | JST-XH 4-pin (VCC/OUT/GND/MODE) | XH-4P | B4B-XH-A(LF)(SN) | C144395 | ✓ | EP | — | XKC-Y26 field connector |

**Notes:** Q1 = 2N7002 `C8545` — **same part as block-4 Q60** (one 2N7002 line item
across the board). R6 = **gate pulldown** (corrected from the archive's "OUT pullup
to 12 V" — XKC output is push-pull, no OUT pull-up needed). XKC-Y26 **MODE = floating**
(JP1 default open) = active-HIGH OUT → active-LOW GPIO after Q1 — **proven by rev1**
(JP4 "normal_open" + firmware active-HIGH, `06` §6.4-3). Sensor **supply = `SENS_12V`**
(switched, resolved). Fails safe toward "don't pump". The XKC-Y26-V sensors themselves
are a mechanical/system BOM item, not on the PCB.

---

# Block 7 — I²C environment sensor + bus pull-ups (BME280)

Design-note: `hardware/rev2/design-notes/07-i2c-env.md` (BME280 pin map, address
0x77, the whole-bus I²C pull-ups, bus address map). **R90/R91 are the only I²C
pull-ups on the board** (§0.7) — the archive omitted them (assumed a module).

| Ref | Qty | Value / part | Package | MPN | LCSC# | St | JLC | Alternatives (≤3) | Role |
|---|---|---|---|---|---|---|---|---|---|
| U6 | 1 | BME280, temp/humidity/pressure | LGA-8 | BME280 (Bosch) | C92489 | ✓ | EP | — | Environment sensor, addr 0x77 (SDO→VDDIO, rev1 parity) |
| R90 | 1 | 4.7 kΩ 1% | 0603 | 0603WAF4701T5E (Uniroyal) | C23162 | ✓ | BP | - | I²C SDA pull-up → +3V3 (whole-bus) |
| R91 | 1 | 4.7 kΩ 1% | 0603 | 0603WAF4701T5E (Uniroyal) | C23162 | ✓ | BP | - | I²C SCL pull-up → +3V3 (whole-bus) |
| C90 | 1 | Ceramic 100 nF, 50 V X7R | 0603 | CC0603KRX7R9BB104 | C14663 | ✓ | BP | — | BME280 VDD decoupling |
| C91 | 1 | Ceramic 100 nF, 50 V X7R | 0603 | CC0603KRX7R9BB104 | C14663 | ✓ | BP | — | BME280 VDDIO decoupling |

**Notes:** U6 BME280 @ **0x77** (SDO→VDDIO, matches rev1 `src/main.cpp:45`); CSB→+3V3
selects I²C. **R90/R91 (4.7 kΩ) are the single I²C pull-up pair** for the whole bus
(BME280 0x77 + pump INA226 0x40 + solar INA226 0x41, all distinct) — confirm
C23162 in plugin (drop to 2.2 kΩ only if rise-time is marginal). C90/C91 reuse the
block-1 100 nF.

---

# Block 8 — Expansion header

Design-note: `hardware/rev2/design-notes/08-expansion.md` (J7 pinout, VSPI-default
flexible GPIO breakout). Resolves the SPI-vs-UART question (not locked in copper —
GPIO-matrix-remappable).

| Ref | Qty | Value / part | Package | MPN | LCSC# | St | JLC | Alternatives (≤3) | Role |
|---|---|---|---|---|---|---|---|---|---|
| J7 | 1 | Pin header 1×8 | 2.54 mm THT | generic (Conn_01x08) | — | — | — | — | Expansion: +3V3/GND/GND + IO18/19/23/4/27 (VSPI default) — KiCad generic, no LCSC import |

**Notes:** J7 breaks out the block-2 §2.2 reserved/spare GPIO (IO18/19/23 native
VSPI + IO4/IO27) with `+3V3` and two `GND`. No strapping pins exposed. **Populated**
(resolved 2026-06-24) — pick a header model in the plugin. Optional ESD/series-R not
placed — the add-on board handles its own protection.

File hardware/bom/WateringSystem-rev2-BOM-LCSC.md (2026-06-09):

# WateringSystem rev2 – BOM (LCSC/JLCPCB)

Komplement till `WateringSystem-rev2-BOM.md` med LCSC-delsnummer för JLCPCB-tillverkning.

**Verifiering:** LCSC-numren nedan har verifierats genom direkt sökning på lcsc.com (2026-05). Komponenter markerade ✓ är bekräftade. Komponenter markerade ⚠️ behöver fortfarande verifieras före beställning (passiva med många alternativ, kontakter med flera modellval, etc).

**JLCPCB Basic vs Extended:**
- **Basic Parts (BP):** förförda i JLCPCB:s placeringsmaskin. Ingen setup-cost.
- **Extended Parts (EP):** kräver setup-cost ~$3 per typ.

---

## Aktiva komponenter

| Ref | MPN | LCSC | JLC-typ | Status | Anmärkning |
|---|---|---|---|---|---|
| U1 | ESP32-WROOM-32E-N4 | **C701341** | Extended | ✓ | 4MB flash. **OBS:** C701343 är N16 (16MB) – se till att välja N4 |
| U2 | CP2102N-A02-GQFN28R | **C964632** | Extended | ✓ | Silicon Labs/Skyworks |
| U3 | THVD1426DRLR | **C5215922** | Extended | ⚠️ | **Ersätter MAX13487E** (C18347) som kräver 5V-matning – rev2 har bara 3.3V-rail. THVD1426 drivs 3–5.5V med samma auto-direction. OBS: LCSC-numret är SOT-5x3-paketet (DRL); SOIC-8 (THVD1426DR) finns hos Mouser/Digikey. Välj paket före footprint. ~$1.10/st, 560 i lager (2026-06) |
| U4 | MP2307DN-LF-Z | **C18921** | Extended | ✓ | MPS officiell |
| U5 | INA226AIDGSR | **C49851** | Extended | ✓ | TI MSOP-10, 19163 i lager, $0.41/st |
| U6 | BME280 | **C92489** | Extended | ✓ | Bosch Sensortec, $3.90/st, 9574 i lager |

## MOSFETs & dioder

| Ref | MPN | LCSC | JLC-typ | Status | Anmärkning |
|---|---|---|---|---|---|
| Q1 | 2N7002 | **C8545** | Basic | ✓ | Jiangsu Changjing 60V 115mA, populär basic part |
| Q2 | **NCE4060K** | **C150550** | Extended | ✓ | **Ersätter AOD514** (finns ej på LCSC). 40V 60A logic-level DPAK, Wuxi NCE Power, $0.09/st |
| Q3 | AO3401A | **C15127** | Basic | ✓ | AOS officiell, $0.034/st |
| D1 | SS54 | **C22452** | Basic | ✓ | MDD Schottky 5A 40V, $0.02/st |
| D2 | SMBJ16CA | **C151255** | Extended | ✓ | Littelfuse officiell |
| D3 | SMBJ15CA | **C78809** | Extended | ✓ | Littelfuse officiell, $0.057/st, 42550 i lager |
| D4 | SM712.TCT | **C12067** | Extended | ✓ | Semtech original RS485-TVS |

### MOSFET-byte AOD514 → NCE4060K

Min ursprungliga rekommendation **AOD514 finns inte på LCSC** (åtminstone inte i 75A-DPAK-versionen). NCE4060K är ett utmärkt alternativ:

| Egenskap | AOD514 (Mouser) | **NCE4060K (LCSC)** |
|---|---|---|
| Vds max | 30V | 40V |
| Id continuous | 75A @ 25°C | 60A @ 25°C |
| Rds(on) @ Vgs=4.5V | 5.8 mΩ | 4.5 mΩ (bättre!) |
| Vgs(th) | 1.5V | 2.0V (fortfarande logic-level @ 3.3V) |
| Paket | DPAK | DPAK |
| Pris | ~$0.50 | ~$0.09 |
| Lager LCSC | – | 1413 |

NCE4060K har **bättre Rds(on)** vid Vgs=4.5V vilket innebär *mindre* värmeförlust vid 15A: P = 15² × 0.0045 = 1.0W (vs 1.3W för AOD514). Ännu bättre val än ursprungligt.

För Mouser-BOM kan AOD514 behållas. Pinout är identisk för båda i DPAK.

## Strömmätning

| Ref | MPN | LCSC | JLC-typ | Status | Anmärkning |
|---|---|---|---|---|---|
| R1, R2 | WPB2512QLR002FYR | **C20350205** | Extended | ✓ | Littelfuse 2mΩ 2W 1% 2512. Marginal 2W>1W – bättre |

## RS485-bus & passiva

| Ref | Värde | LCSC | JLC-typ | Status |
|---|---|---|---|---|
| R3 | 120 Ω 0603 | **C22787** | Basic | ✓ |
| R4, R5 | 680 Ω 0603 | **C23253** | Basic | ✓ |
| R6, R7, R8, R11 | 10 kΩ 0603 | **C25804** | Basic | ✓ |
| R9 | 100 Ω 0603 | **C22775** | Basic | ✓ |
| R10 | 5.1 kΩ 0603 | **C23186** | Basic | ✓ |
| R12 | 1 kΩ 0603 | **C21190** | Basic | ✓ |

(Alla passiva är Yageo Basic Parts på JLCPCB – ingen setup-cost.)

## Kondensatorer

| Ref | Värde | Paket | LCSC | JLC-typ | Status |
|---|---|---|---|---|---|
| C1 | 10 µF 25V | 0805 | **C45783** | Basic | ✓ |
| C2 | 22 µF 10V | 0805 | (välj alternativ) | Basic | ⚠️ Verifiera 22µF/10V-LCSC – C45783 är 10µF |
| C3 | 100 nF 16V | 0402 | **C1525** | Basic | ✓ |
| C5 | 470 µF 25V | SMD elec | (välj alternativ) | Extended | ⚠️ Många alternativ på LCSC |

**Anmärkning C2:** Korrigera till en faktisk 22µF/10V/0805 – t.ex. **C45783** är 10µF (samma som C1). Sök på LCSC efter "22uF 10V 0805 X5R" – populära är CL21A226MQQNNNE.

## Induktor & säkring

| Ref | Komponent | LCSC | JLC-typ | Status |
|---|---|---|---|---|
| L1 | 22 µH 3A shielded | **C3911669** | Extended | ⚠️ MSS1278-223MLD är 12×12mm (stort). Mindre alternativ finns – kolla 7×7mm- eller 5×5mm-versioner @ 3A |
| F1 | Polyfuse 1812 | **C3762102** (0ZCG0050AF2C) | Extended | ⚠️ Bel Fuse, 500mA hold-current. För 1A hold-current: sök "1812 PTC 1A" |

## LEDs & switchar

| Ref | Komponent | LCSC | JLC-typ | Status |
|---|---|---|---|---|
| LED1 | LED grön 0603 | **C72043** | Basic | ⚠️ Verifiera exakt MPN |
| LED2 | LED röd 0603 | **C72041** | Basic | ⚠️ Verifiera exakt MPN |
| SW1, SW2 | Tactile switch SMD | **C318884** | Extended | ⚠️ Verifiera tactile-switch-modell |

## Kontakter

| Ref | Komponent | LCSC | JLC-typ | Status |
|---|---|---|---|---|
| J1 | TYPE-C-31-M-12 | **C165948** | Extended | ✓ Korean Hroparts, 117930 i lager |
| J2, J3 | 2-pin terminal block 5.08mm | (välj) | Extended | ⚠️ Du sa Weidmüller – välj specifik modell |
| J4, J5 | B4B-XH-A(LF)(SN) | **C144395** | Extended | ✓ JST original, 332830 i lager |
| J6 | 2.54mm 6-pin header | (välj) | Basic | ⚠️ Generisk pin-header |

---

## Sammanfattning av ändringar från första utkastet

Verifierings-passet hittade flera fel i ursprungliga LCSC-numren:

| Ref | Före | Efter | Anledning |
|---|---|---|---|
| U1 | C701343 | **C701341** | C701343 är N16 (16MB), du vill ha N4 (4MB) |
| U2 | C150228 | **C964632** | Aktuellt LCSC-nummer för CP2102N-A02-GQFN28R |
| U3 | C144059 | **C18347** | Faktiskt LCSC-nummer för MAX13487EESA+T |
| U4 | C9100 | **C18921** | C18921 är MP2307DN-LF-Z; C9100 är annan variant |
| U5 | C100069 | **C49851** | Aktuellt TI INA226AIDGSR-nummer |
| U6 | C90465 | **C92489** | Aktuellt Bosch BME280-nummer |
| Q1 | C8581 | **C8545** | Jiangsu Changjing version (LCSC populär basic) |
| **Q2** | C155570 (AOD514) | **C150550 (NCE4060K)** | AOD514 finns ej på LCSC; NCE4060K är bättre |
| D2 | C39381 | **C151255** | Littelfuse SMBJ16CA officiell |
| D3 | C39379 | **C78809** | Littelfuse SMBJ15CA officiell |
| D4 | C113862 | **C12067** | Semtech SM712.TCT officiell |
| R1, R2 | C195811 | **C20350205** | Littelfuse WPB2512QLR002FYR (2mΩ 2W) |
| J4, J5 | C144394 | **C144395** | Korrekt JST B4B-XH-A(LF)(SN) |

---

## JLCPCB EMS-strategi (oförändrad från tidigare utkast)

1. **Kontrollera parts library** på https://jlcpcb.com/parts – sök varje LCSC-nummer för aktuell lagerstatus
2. **Kritiska komponenter att dubbelkolla först:**
   - MAX13487E (Extended) – om out-of-stock: byt till MAX13488E eller fall tillbaka till MAX3485 + GPIO25
   - NCE4060K (Extended) – om out-of-stock: NCE3080K, AON6266 eller AOD417 är möjliga alternativ
   - SM712.TCT – om out-of-stock: SMAJ12CA-par över A/B fungerar likvärdigt
3. **Fabrication Toolkit-plugin** (redan installerat enligt `hardware/fabrication-toolkit-options.json`):
   - Lägg `LCSC`-fält i KiCad-symbolerna med värden från tabellen ovan
   - Kör plugin → genererar Gerbers + BOM.csv + CPL.csv i `hardware/jlcpcb/`
   - Ladda upp ZIP på jlcpcb.com → toggle "PCB Assembly" → upload BOM + CPL → JLCPCB matchar automatiskt

## Estimerad kostnad (5 monterade kort hos JLCPCB)

| Post | Kostnad |
|---|---|
| 5× PCB 4-lager 100×80mm | ~$25 |
| Stencil | ~$15 |
| Assembly setup | $8 |
| Extended parts setup (~12 typer × $3) | ~$36 |
| Komponenter (5× kort × ~$25) | ~$125 |
| **Totalt** | **~$210** ($42/kort) |

För större volymer (>20st) sjunker priset markant eftersom setup-cost är fast.

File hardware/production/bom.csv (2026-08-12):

Designator | Footprint | Quantity | Value | LCSC Part #
J1, J3 | JST_XH_B4B-XH-A_1x04_P2.50mm_Vertical | 2 | RESERVOIR_SENSOR_LOW
J2, J4 | JST_XH_B4B-XH-A_1x04_P2.50mm_Vertical | 2 | RESERVOIR_SENSOR_HIGH

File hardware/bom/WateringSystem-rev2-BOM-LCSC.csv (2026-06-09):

Reference | Quantity | Value | Footprint | MPN | LCSC | JLCPCB_Type | Description | Verified
U1 | 1 | ESP32-WROOM-32E-N4 | Module | ESP32-WROOM-32E-N4 | C701341 | Extended | ESP32 module 4MB flash | Yes
U2 | 1 | CP2102N | QFN-28 | CP2102N-A02-GQFN28R | C964632 | Extended | USB-to-UART bridge | Yes
U3 | 1 | THVD1426 | SOT-5x3 (DRL) | THVD1426DRLR | C5215922 | Extended | RS485 auto-direction 3-5.5V (ersätter MAX13487E som kräver 5V). OBS SOT-paket hos LCSC - SOIC-8 (THVD1426DR) via Mouser/Digikey | Yes
U4 | 1 | MP2307DN-LF-Z | SOIC-8-EP | MP2307DN-LF-Z | C18921 | Extended | Buck 4.75-23V in 3A out | Yes
U5 | 2 | INA226AIDGSR | MSOP-10 | INA226AIDGSR | C49851 | Extended | Current/voltage monitor I2C 16-bit | Yes
U6 | 1 | BME280 | LGA-8 | BME280 | C92489 | Extended | Temp/humidity/pressure sensor Bosch | Yes
Q1 | 2 | 2N7002 | SOT-23 | 2N7002 | C8545 | Basic | N-MOSFET 60V 115mA (Jiangsu Changjing) | Yes
Q2 | 2 | NCE4060K | DPAK (TO-252) | NCE4060K | C150550 | Extended | N-MOSFET 40V 60A logic-level (ersätter AOD514) | Yes
Q3 | 1 | AO3401A | SOT-23 | AO3401A | C15127 | Basic | P-MOSFET reverse-polarity | Yes
D1 | 2 | SS54 | SMA | SS54 | C22452 | Basic | Schottky 5A 40V (MDD) | Yes
D2 | 2 | SMBJ16CA | SMB | SMBJ16CA | C151255 | Extended | TVS bidirectional 16V (Littelfuse) | Yes
D3 | 1 | SMBJ15CA | SMB | SMBJ15CA | C78809 | Extended | TVS bidirectional 15V (Littelfuse) | Yes
D4 | 1 | SM712.TCT | SOT-23 | SM712.TCT | C12067 | Extended | RS485 TVS array (Semtech) | Yes
L1 | 1 | 22uH | SMD power inductor | (välj) | C3911669 | Extended | Coilcraft MSS1278-223MLD eller alternativ | Partial
R1 | 1 | 2 mOhm 2W | 2512 | WPB2512QLR002FYR | C20350205 | Extended | Current shunt 2mΩ 1% 2W (Littelfuse) | Yes
R2 | 1 | 2 mOhm 2W | 2512 | WPB2512QLR002FYR | C20350205 | Extended | Current shunt 2mΩ 1% 2W (Littelfuse) | Yes
R3 | 1 | 120R | 0603 | (0603WAF1200T5E) | C22787 | Basic | RS485-terminering | Yes
R4 | 1 | 680R | 0603 | (0603WAF6800T5E) | C23253 | Basic | RS485 bias-pullup | Yes
R5 | 1 | 680R | 0603 | (0603WAF6800T5E) | C23253 | Basic | RS485 bias-pulldown | Yes
R6 | 2 | 10k | 0603 | (0603WAF1002T5E) | C25804 | Basic | XKC-Y26 OUT pullup | Yes
R7 | 2 | 10k | 0603 | (0603WAF1002T5E) | C25804 | Basic | 2N7002 drain pullup | Yes
R8 | 2 | 10k | 0603 | (0603WAF1002T5E) | C25804 | Basic | AOD514 gate-pulldown | Yes
R9 | 2 | 100R | 0603 | (0603WAF1000T5E) | C22775 | Basic | NCE4060K gate-resistor | Yes
R10 | 2 | 5.1k | 0603 | (0603WAF5101T5E) | C23186 | Basic | USB-C CC1/CC2 pulldown | Yes
R11 | 2 | 10k | 0603 | (0603WAF1002T5E) | C25804 | Basic | EN/BOOT pullups | Yes
R12 | 1 | 1k | 0603 | (0603WAF1001T5E) | C21190 | Basic | Power LED limit | Yes
C1 | 4 | 10uF 25V | 0805 | (CL21A106KQQNNNE) | C45783 | Basic | Buck input + bypass | Yes
C2 | 2 | 22uF 10V | 0805 | (CL21A226KOQNNNE) | C45783 | Basic | Buck output cap (3.3V) | Partial
C3 | 5 | 100nF 16V | 0402 | (CL05B104KO5NNNC) | C1525 | Basic | Bypass per IC | Yes
C5 | 1 | 470uF 25V | SMD electrolytic | (välj alternativ) | C134781 | Extended | Bulk input cap - verifiera modell | Partial
SW1 | 1 | Tactile switch | SMD 6x6mm | TS-1187A-B-A-B | C318884 | Extended | BOOT-knapp | Partial
SW2 | 1 | Tactile switch | SMD 6x6mm | TS-1187A-B-A-B | C318884 | Extended | RESET-knapp | Partial
J1 | 1 | USB-C receptacle | 16-pin SMD | TYPE-C-31-M-12 | C165948 | Extended | USB-C connector (Korean Hroparts) | Yes
J2 | 1 | 2-pin terminal block | 5.08mm pitch | (Weidmüller) | (välj) | Extended | 12V-input (XY308V eller annan) | No
J3 | 2 | 2-pin terminal block | 5.08mm pitch | (Weidmüller) | (välj) | Extended | Pump output | No
J4 | 1 | JST XH 4-pin | XH-4P | B4B-XH-A(LF)(SN) | C144395 | Extended | Soil-sensor (RS485) | Yes
J5 | 2 | JST XH 4-pin | XH-4P | B4B-XH-A(LF)(SN) | C144395 | Extended | Nivåsensorer XKC-Y26 | Yes
J6 | 1 | JTAG header 6-pin | 2.54mm | (generic) | C2337 | Basic | JTAG header | Partial
LED1 | 1 | LED grön | 0603 | 17-21SUGC | C72043 | Basic | Power-indikator | Partial
LED2 | 1 | LED röd | 0603 | 17-21SURC | C72041 | Basic | Status-LED | Partial
F1 | 1 | Polyfuse 1A | 1812 | (välj alternativ) | C3762102 | Extended | 0ZCG0050AF2C Bel Fuse eller alternativ | Partial

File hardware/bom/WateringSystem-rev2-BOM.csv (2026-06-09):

Reference | Quantity | Value | Footprint | Manufacturer | MPN | Description | Notes
U1 | 1 | ESP32-WROOM-32E | Module | Espressif | ESP32-WROOM-32E-N4 | ESP32 module, 4MB flash, PCB antenna | Behåll samma modul som idag
U2 | 1 | CP2102N | QFN-28 | Silicon Labs | CP2102N-A02-GQFN28R | USB-to-UART bridge | Auto-program-krets med 2x 2N3904
U3 | 1 | THVD1426 | SOIC-8 | Texas Instruments | THVD1426DR | RS485 transceiver, auto-direction, 3-5.5V supply | Ingen DE-pin behövs - bias-resistorer R4/R5 krävs
U4 | 1 | MP2307DN | SOIC-8-EP | Monolithic Power | MP2307DN | Buck converter, 4.75-23V in, 0.925-15V out, 3A | 12V till 3.3V
U5 | 2 | INA226AIDGSR | MSOP-10 | Texas Instruments | INA226AIDGSR | Current/voltage/power monitor, 16-bit, I2C | En per pump - olika I2C-adress via A0/A1
U6 | 1 | BME280 | LGA-8 | Bosch | BME280 | Temp/humidity/pressure sensor, I2C | Behåll - samma som idag
Q1 | 2 | 2N7002 | SOT-23 | Onsemi | 2N7002LT1G | N-MOSFET 60V 200mA | Level-shift XKC-Y26 OUT till 3.3V
Q2 | 2 | AOD514 | DPAK (TO-252) | Alpha & Omega | AOD514 | N-MOSFET 30V 75A logic-level | Pump-switch (huvudpump + reservoarpump)
Q3 | 1 | AO3401 | SOT-23 | Alpha & Omega | AO3401A | P-MOSFET 30V 4A | Reverse-polarity-skydd på 12V-input
D1 | 2 | SS54 | SMA | Onsemi | SS54 | Schottky 5A 40V | Flyback-diod över pump
D2 | 2 | SMBJ16CA | SMB | Littelfuse | SMBJ16CA | TVS bidirectional 16V | Skydd över AOD514 drain-source
D3 | 1 | SMBJ15CA | SMB | Littelfuse | SMBJ15CA | TVS bidirectional 15V | Skydd på 12V-input-rail
D4 | 1 | SM712 | SOT-23 | Semtech | SM712 | RS485 TVS array 7/12V | Skydd över A/B på RS485-buss
L1 | 1 | 22uH | SMD power inductor | Coilcraft | XAL5030-223MEC | 22uH 3A power inductor | För MP2307 buck
R1 | 1 | 2 mΩ 1W | 2512 | Susumu | KRL3216E-C-R002-F-T1 | Current shunt 2mΩ 1% 1W | I serie med pump - krymp BOM med en per pump om delade INA226
R2 | 1 | 2 mΩ 1W | 2512 | Susumu | KRL3216E-C-R002-F-T1 | Current shunt 2mΩ 1% 1W | Andra pumpens shunt
R3 | 1 | 120Ω 1/8W | 0603 | Yageo | RC0603FR-07120RL | RS485-terminering | Mellan A och B
R4 | 1 | 680Ω 1/8W | 0603 | Yageo | RC0603FR-07680RL | RS485 bias-pullup | A till 3.3V
R5 | 1 | 680Ω 1/8W | 0603 | Yageo | RC0603FR-07680RL | RS485 bias-pulldown | B till GND
R6 | 2 | 10kΩ 1/8W | 0603 | Yageo | RC0603FR-0710KL | XKC-Y26 OUT pullup till 12V | En per nivåsensor
R7 | 2 | 10kΩ 1/8W | 0603 | Yageo | RC0603FR-0710KL | 2N7002 drain pullup till 3.3V | En per nivåsensor
R8 | 2 | 10kΩ 1/8W | 0603 | Yageo | RC0603FR-0710KL | AOD514 gate-pulldown | Säker av under boot
R9 | 2 | 100Ω 1/8W | 0603 | Yageo | RC0603FR-07100RL | AOD514 gate-resistor | Begränsar switching-transient
R10 | 2 | 5.1kΩ 1/8W | 0603 | Yageo | RC0603FR-075K1L | USB-C CC1/CC2 pulldown | För source-detection
R11 | 2 | 10kΩ 1/8W | 0603 | Yageo | RC0603FR-0710KL | EN/BOOT pullups | För ESP32 boot-konfiguration
C1 | 4 | 10uF 25V | 0805 | Murata | GRM21BR61E106KA73L | Buck input cap | 2 på 12V-rail nära MP2307
C2 | 2 | 22uF 10V | 0805 | Murata | GRM21BR61A226KE51L | Buck output cap | 3.3V efter buck-induktor
C3 | 1 | 100nF 16V | 0402 | Murata | GRM155R61C104KA88D | Bypass-cap på alla IC | Sätt 1 per IC nära VCC
C4 | 4 | 100nF 16V | 0402 | Murata | GRM155R61C104KA88D | Bypass-cap på alla IC | En per IC
C5 | 1 | 470uF 25V | SMD electrolytic | Nichicon | UWT1E471MNL1GS | Bulk input cap | Stora transienter från pumpstart
SW1 | 1 | Tactile switch SMD | SMD 6x6mm | C&K | PTS636SK50SMTR LFS | BOOT-knapp | Till GPIO0
SW2 | 1 | Tactile switch SMD | SMD 6x6mm | C&K | PTS636SK50SMTR LFS | RESET-knapp | Till EN
J1 | 1 | USB-C receptacle | 16-pin SMD | GCT | USB4105-GF-A | USB-C connector | För programmering och ström alternativt
J2 | 1 | 2-pin terminal block | 5.08mm pitch | Weidmüller | Per användares val | 12V-input | Användare väljer modell
J3 | 2 | 2-pin terminal block | 5.08mm pitch | Weidmüller | Per användares val | Pump output | En per pump
J4 | 1 | JST XH 4-pin | XH-4P | JST | B4B-XH-A(LF)(SN) | Soil-sensor (RS485) | A/B/12V/GND
J5 | 2 | JST XH 4-pin | XH-4P | JST | B4B-XH-A(LF)(SN) | Nivåsensorer XKC-Y26 | VCC/OUT/GND/MODE
J6 | 1 | JTAG 6-pin header | 0.1" pitch | Generic | Per användares val | JTAG för ESP-IDF debug | GPIO12-15 + GND/3.3V
LED1 | 1 | LED grön | 0603 | Lite-On | LTST-C190KGKT | Power-indikator | På 3.3V via 1k resistor
LED2 | 1 | LED röd | 0603 | Lite-On | LTST-C190KRKT | Status-LED | På GPIO2
F1 | 1 | Polyfuse 1A | 1812 | Bel Fuse | 0ZCJ0100AF2C | Resettable fuse på 12V-input | Skydd mot kortslutning

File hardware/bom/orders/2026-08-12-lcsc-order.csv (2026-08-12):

LCSC Part Number | Quantity | Manufacturer Part Number | Designator | Description
C400894 | 5 | AOD4185 (AOS) | Q20 | P-MOSFET −40 V, ≤10 mΩ
C15127 | 5 | AO3401A | Q21 | P-MOSFET −30 V
C78409 | 5 | SMBJ15A/TR13 (Brightking) | D20 | TVS unidir, 15 V standoff, 600 W
C216719 | 6 | BZT52C10 | D21 D22 | Zener 10 V, 500 mW
C6674609 | 2 | MP2393GTL-Z | U4 | Buck 3 A COT, 4.2–24 V in, PG+SS
C5189747 | 5 | CYA0630-3.3UH (SHOU HAN) | L20 | Power inductor 3.3 µH, ≥4 A sat, shielded
C72477 | 5 | RVT1E101M0607 (ROQANG) | C20 | Electrolytic 100 µF, 25 V
C89632 | 20 | CL31B106KBHNNNE (50V) | C21 C22 | Ceramic X7R 10 µF, ≥25 V
C14663 | 100 | CC0603KRX7R9BB104 | C28 C29 C32 C41 C51 C53 C60 C70 C90 C91 | Ceramic 0.1 µF, 50 V X7R
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

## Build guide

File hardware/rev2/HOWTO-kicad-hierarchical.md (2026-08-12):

# HOWTO — modular hierarchical design in KiCad 10 (rev2)

A from-scratch walkthrough of the workflow described in
`design-notes/00-architecture.md`, using the **power** module as the worked
example. Assumes KiCad 10.0.x and no prior hierarchical-sheet experience.

> Menu wording can shift slightly between point releases. Where a hotkey is
> given it is the KiCad default; check **Preferences → Hotkeys** if it differs.

---

## 0. Mental model (read once)

- The **root sheet** holds no parts — only one box ("sheet symbol") per module.
- Each **module** is its own `.kicad_sch` file with the actual components.
- A module's **interface** is its *hierarchical pins*. You make a pin by placing
  a **hierarchical label** *inside* the module; that label then appears as a pin
  on the module's box in the root sheet, where you wire it.
- **Power and ground are not pins.** You place a **power symbol** (`GND`, `+3V3`,
  custom `VBAT`, `SENS_12V`) wherever a rail is needed; KiCad joins all symbols
  of the same name everywhere. One `PWR_FLAG` per rail tells ERC the rail is fed.

So: signals travel through pins (visible wiring on the root sheet); rails travel
by name (invisible, via power symbols). This is the whole trick.

---

## 1. Create the rev2 project

1. **KiCad → File → New Project** → save as
   `hardware/rev2/WateringSystem-rev2.kicad_pro`. (Separate project from the
   rev1 `hardware/` one — see `00-architecture.md` §0.2.)
2. Open the **Schematic Editor**. The blank page that opens *is* the root sheet
   (`WateringSystem-rev2.kicad_sch`).
3. Fill in the title block (bottom-right): **File → Page Settings**. Set title
   "WateringSystem rev2 — root".

## 2. Create the power module sheet

1. On the root sheet: **Place → Add Hierarchical Sheet** (hotkey `S`). Click two
   corners to draw a box.
2. In the dialog: **Sheet name** = `power`, **File name** = `power.kicad_sch`.
   OK. You now have an empty module referenced from the root.
3. **Double-click the box** to enter the power sheet. (The breadcrumb at the top
   shows `Root » power`; double-click empty space or use the up-arrow to go
   back.)

## 3. Draw the power module (per `design-notes/01-power.md`)

Inside `power.kicad_sch`:

1. **Place symbols** (`A` = Add Symbol) for the BOM parts this module owns: J2,
   the buck U4 (MP2307) + L1 + caps, reverse protection + TVS, the battery-sense
   divider, the `SENS_12V` high-side FET, LED1. Wire them per the connectivity
   tables in `01-power.md` §1.1–§1.5.
   - If a symbol/footprint isn't in the stock libraries (MP2307, THVD1426,
     ESP32-WROOM, INA226), grab it from the manufacturer or SnapEDA and add it
     via **Preferences → Manage Symbol Libraries**. Do this per part as you go.
2. **Place the rails it *produces*** as power symbols (`P` = Add Power Symbol):
   `+3V3` on the buck output, `GND` on grounds, and custom symbols `VBAT` and
   `SENS_12V`. If `VBAT`/`SENS_12V` aren't in the power library, make them: any
   power symbol can be renamed, or copy `+12V` and relabel.
3. **Add one `PWR_FLAG`** each on `VBAT`, `+3V3`, `SENS_12V`, `GND` at the point
   the power module generates them (e.g. `PWR_FLAG` on the buck output net for
   `+3V3`). This is what stops ERC complaining the rails are unfed.

## 4. Define the module's interface (hierarchical labels)

Still inside `power.kicad_sch`, place a **hierarchical label** (Place → Add
Hierarchical Label, hotkey `H`) on each signal that must reach another module —
from `00-architecture.md` §0.5 *power*:

| Label | Shape / direction | Attach to |
|---|---|---|
| `SENS_GATE` | input | gate of the `SENS_12V` high-side FET |
| `VBAT_SENSE` | output | midpoint of the battery-sense divider |
| `I2C_SDA` | bidirectional | only if the solar INA226 is populated (DNP) |
| `I2C_SCL` | bidirectional | only if the solar INA226 is populated (DNP) |

The label *shape* (input/output/bidir) is cosmetic but set it to match the
table — it documents direction and makes the root sheet readable. Do **not**
make hierarchical labels for `VBAT`/`3V3`/`GND`/`SENS_12V` — those are rails
(step 3), not pins.

## 5. Run ERC on the module in isolation

**Inspect → Electrical Rules Checker → Run**. Fix everything before integrating.
Common first-pass items for power: missing `PWR_FLAG`, an unconnected pin you
meant to leave open (mark it with a **no-connect flag**, `Q`), the `VBAT_IN` vs
`VBAT` short check from `01-power.md` (ERC won't catch a bypassed protection
FET — eyeball it).

## 6. Wire the module into the root sheet

1. Go back up to the root sheet.
2. The `power` box now needs its **sheet pins** — one per hierarchical label.
   Right-click the box → **Import Sheet Pins** (or Place → Add Sheet Pin and
   pick from the list). `SENS_GATE`, `VBAT_SENSE`, (`I2C_*`) appear on the box.
   - KiCad 9/10 has a **sheet-pin ↔ hierarchical-label sync** tool so the two
     stay matched if you rename later — use it instead of hand-editing pins.
3. Draw wires from each sheet pin toward where its partner module will sit
   (you'll connect them once those modules exist). For now you can drop a
   matching **hierarchical label** on the root-sheet wire end, or leave a stub.
4. Place the **global rails** on the root sheet too if any root-level part needs
   them; mostly the rails just propagate by name once `power` sources them.

## 7. Annotate + assign footprints

1. **Tools → Annotate Schematic** — assigns refdes. KiCad re-annotates freely;
   the `00-architecture.md` / `01-power.md` numbering is the connectivity source
   of truth, not a hard requirement on KiCad's numbers.
2. **Tools → Assign Footprints** (or per-symbol in its properties). Match the
   packages in the rev2 BOM (SOIC-8-EP for U4, 2512 for the shunt, etc.).
3. Re-run ERC at the root level.

## 8. Save the module as a Design Block (reuse — the payoff)

Once `power` is stable and ERC-clean:

1. Open the **Design Blocks** panel in the Schematic Editor (**View → Panels →
   Design Blocks** if hidden). **Create the library from inside the panel:**
   right-click in the panel → **New Library** → choose scope **global** (visible
   to all projects — the point of the exercise) and point the path somewhere
   shareable, *not* inside a single project folder. **Chosen (2026-07-02):**
   `${KICAD10_3RD_PARTY}/lib/embedded_blocks.kicad_blocks` — the KiCad path
   variable keeps the entry portable. One library, many blocks: every module
   (power, mcu, …) is saved as its own block *inside* this one library, and the
   §9 PCB layout blocks go to the same library/block names (that is what links
   schematic ↔ layout). This creates the `.kicad_blocks` folder on disk AND the
   library-table entry in one go (no need to touch Preferences → Manage Design
   Block Libraries manually — that dialog only *registers* existing folders, it
   never creates them).
   On disk: the library is a folder `Name.kicad_blocks`; each saved block becomes
   a subfolder `blockname.kicad_block` holding a `.kicad_sch` (+ `.kicad_pcb` for
   layout blocks) and a `.json` with metadata.
   ⚠️ Avoid the panel's "hide library tree" button — it hides the whole panel
   (restore via View → Panels → Design Blocks).
2. Inside the sheet: **Ctrl+A** — select *everything*, **including the
   hierarchical labels, power symbols and PWR_FLAGs**, not just the components.
   The labels ARE the module interface: they become the sheet pins when the block
   is reused (Import Sheet Pins), and the power symbols self-connect to the target
   project's global rails. (PWR_FLAGs travel with the *power* block only — one per
   net per board; the other blocks have none.) Then right-click → **Save Selection
   as Design Block** (or the panel's save button). Name it `power-12v-buck`.
   Refdes numbers don't matter — the target project re-annotates.
3. To reuse in a future board: open that project's Design Blocks panel and drop
   `power-12v-buck` in. It comes in as an independent copy with its interface
   intact.

## 9. PCB — module-by-module layout + the layout design block (KiCad 10)

**There is no per-sheet import** — `Update PCB from Schematic` (F8) always brings
in *all* footprints. But you never hand-sort: KiCad clusters and selects by
hierarchical sheet for you. The per-module loop:

### 9.1 One-time import
1. Root-level **ERC clean** first, and every symbol must have a footprint
   (Fabrication Toolkit parts have them; check the generics: J2/J3/J8/J9 terminal
   blocks, J6/J7 pin headers, JP1/JP2 `SolderJumper` footprints).
2. PCB editor → **Tools → Update PCB from Schematic (F8)**. All new footprints
   arrive attached to the cursor, **already clustered by schematic sheet** (and by
   position within the sheet). Drop the whole heap outside the board outline.

### 9.2 Per module — gather, place, route
1. **Grab one sheet's parts:** right-click any footprint from the module →
   **Select → Items in Same Hierarchical Sheet**. (Alternative from the schematic
   side: select the parts in the sheet → right-click → **Select on PCB** —
   cross-probing selects the matching footprints.)
2. **Pack and Move Footprints (`P`)** on that selection — KiCad packs them into a
   tight cluster on the cursor; drop it in its own staging area.
3. Lay the module out there: decoupling tight at IC pins, the loops per the
   design-note layout hints (buck loop `01` §1.2, pump switch loop `05` §5.2.1,
   D50/D4 at their connectors, Q2/Q20 copper pours).
4. Route the module's *internal* nets. Leave inter-module nets (rails, the §0.5
   signals) unrouted — they are routed once modules are placed on the board.
5. Select the finished cluster (step 1 again) → right-click → **Group**.

### 9.3 Save as PCB design block (the reuse payoff)
1. With the group selected → save as a **PCB Design Block** into the shared
   library (same one as the schematic blocks, e.g.
   `hardware/lib/WateringSystem` — Design Blocks panel in the PCB editor).
   The schematic group's *library link* carries over, tying layout ↔ schematic
   blocks together.
2. In a future board, recall the block: whole placement + routing comes back as
   one independent copy — caps already by the pins.

### 9.4 Board integration
Once all modules exist as placed groups: drag the groups into position inside the
board outline (a group moves as one unit), then route the inter-module nets
(rails + §0.5 signals) and pour GND.

> For *this* single-pump node there's only one of each module, so step 9 is
> about future reuse, not this board. If a later board has repeated channels
> (multi-pump), use **multi-channel design** to replicate one channel's layout
> across instances within that project.

---

## Quick reference — the loop per module

```
root: Add Hierarchical Sheet  →  enter sheet
  └ place parts + wire (per NN-*.md)
  └ place rails as power symbols (+ one PWR_FLAG each)
  └ place hierarchical labels for the interface signals
  └ ERC the sheet
root: Import Sheet Pins  →  wire pins to neighbour modules
annotate → assign footprints → root ERC
save stable module as a Design Block
```

Next module after power: **mcu** + **usb-uart** (see `00-architecture.md` §0.8
build order).

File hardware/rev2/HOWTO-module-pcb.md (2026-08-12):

# HOWTO — build rev2 as separate module PCBs (stage A)

How to turn the existing hierarchical schematic into **one small PCB per block**,
hand-assembled on a hot plate and interconnected with 2.54 mm headers. This is
the stage-A prototype path decided in `design-notes/09-prototype-modules.md`.

**Relation to the other docs — read this first:**

| Doc | Covers |
|---|---|
| `HOWTO-kicad-hierarchical.md` | How the hierarchical schematic was drawn; §9 = per-module layout **on one integrated board** (that is stage B) |
| `design-notes/09-prototype-modules.md` | *Why* modules first, bring-up order |
| **this file** | *How* to produce the module boards from the same schematic |

Core rule: **the schematic is drawn once.** Module projects reuse the existing
`*.kicad_sch` block files by reference — they are never copied, never forked.
Only layout is done twice (module boards now, integrated board later).

---

## 1. Preflight — blockers to clear before starting

1. **Four symbols still have no footprint.** `Update PCB from Schematic` (F8)
   refuses to run until every symbol has one. Names verified against the
   KiCad 10 libraries on disk 2026-08-12:

   | Symbol | Sheet | Footprint |
   |---|---|---|
   | `J6` (JTAG 1×6, DNP) | mcu | `Connector_PinHeader_2.54mm:PinHeader_1x06_P2.54mm_Vertical` |
   | `J7` (expansion 1×8) | expansion | `Connector_PinHeader_2.54mm:PinHeader_1x08_P2.54mm_Vertical` |
   | `JP1`, `JP2` (MODE) | level-sensors | `Jumper:SolderJumper-2_P1.3mm_Open_TrianglePad1.0x1.5mm` |

   Solder-jumper choice: **Open** matches the design default (floating MODE =
   active-HIGH, `06` §6.3); the **TrianglePad** variant is the easiest of the
   three open variants to bridge with an iron after assembly.

   Assign these in the block sheets (they belong to the design, not to the
   prototype) so stage B inherits them.
2. **Off-LCSC parts** — the LCSC order will NOT cover these; source separately:
   Weidmüller 1715010000 ×4 (J2 battery, J3 pump, J8/J9 panel), and the generic
   pin headers. See §9.
3. Close KiCad before any scripted edit; stale `~*.lck` files are gitignored but
   a second KiCad instance on the same sheet file will fight you.

## 2. Mental model

A module project is a **thin wrapper**:

```
mod-power.kicad_sch  (root, lives in the module project)
   ├── sheet symbol → ../../power.kicad_sch      ← THE shared block sheet
   └── J100/J101 headers, wired to the sheet pins + rail power symbols
```

The block sheet is untouched. Its hierarchical labels (the §0.5 pin contract)
become sheet pins on the wrapper root, and there you wire them out to headers.
Rails (`VBAT`, `+3V3`, `GND`, `SENS_12V`) travel by name as always, so on the
wrapper you place a power symbol on the header pin that carries each rail.

**Why this works:** KiCad stores symbol *instance* data (reference, unit) per
project inside the sheet file — one `(project "…")` entry each. The integrated
project and every module project coexist in the same file without collision.

**Why not Design Blocks** (`HOWTO-kicad-hierarchical.md` §8): a design block is
dropped in as an **independent copy**. Great for a future *different* board,
wrong here — a fix found during bring-up would have to be applied twice and the
two would drift. Reference, don't copy.

## 3. Directory layout

```
hardware/rev2/
  power.kicad_sch  mcu.kicad_sch  …          ← shared block sheets (unchanged)
  modules/
    mod-power/     mod-power.kicad_pro/.kicad_sch/.kicad_pcb
    mod-mcu/       …
```

Keep the depth exactly two levels down — the sheet reference
`../../power.kicad_sch` is stored relative to the project.

## 4. What to build

Eight blocks → **six boards**. Two groupings, both deliberate:

| Module board | Blocks | Why grouped |
|---|---|---|
| `mod-power` | 1 | — |
| `mod-mcu` | 2 + 3 + 8 | The auto-reset circuit spans mcu/usb-uart (`03` §3.3.5); splitting it puts the EN/BOOT timing across a jumper. Expansion (8) is just J7 — no board of its own. |
| `mod-rs485` | 4 | — |
| `mod-pump` | 5 | — |
| `mod-level` | 6 | — |
| `mod-i2c-env` | 7 | Owns the bus pull-ups — keep it on the bench for every I²C test |

## 5. Per-module recipe (worked example: `mod-power`)

1. **New project** → `hardware/rev2/modules/mod-power/mod-power.kicad_pro`.
2. **Reference the block sheet:** in the root schematic, `Place → Add
   Hierarchical Sheet` (`S`), draw the box, and set **File name** =
   `../../power.kicad_sch`. KiCad warns the file already exists and asks whether
   to use it — **yes, use the existing file.** Sheet name: `power`.
3. **Import Sheet Pins:** right-click the box → *Import Sheet Pins*. For power
   you get `SENS_GATE`, `VBAT_SENSE`, `PWR_PG`, `I2C_SDA`, `I2C_SCL`.
4. **Place the headers** (see §6 for the pinout convention) and wire each sheet
   pin to its header pin.
5. **Rails on the wrapper:** place a power symbol (`P`) on each rail pin of the
   rail header — `VBAT`, `+3V3`, `GND`, `SENS_12V` for power.
   - A module that **consumes** a rail through a header needs **one `PWR_FLAG`**
     on that header pin, or ERC reports "power input not driven". `mod-power`
     *produces* its rails and already carries the PWR_FLAGs inside block 1 — do
     not add a second set here.
6. **Annotate — carefully.** `Tools → Annotate` with **"Keep existing
   annotation"**. The block parts must keep their master-BOM refdes (U4, L20,
   C20…) or the BOM, the assembly and every design note stop matching. Headers
   are new parts: give them the **J100+ series**, which exists only on prototype
   boards.
7. **ERC** at root. Expect: unconnected sheet pins you chose not to break out
   (mark with a no-connect flag `Q` on the wrapper, never inside the block
   sheet), and the PWR_FLAG item from step 5.
8. **PCB:** F8 → all footprints arrive clustered by sheet. Draw an `Edge.Cuts`
   outline (see §7), add 4× M3 mounting holes, place and route per §8.
9. **DRC clean**, then Fabrication Toolkit export (§9).

Repeat per module. After the first one the loop takes minutes — the schematic
work is already done.

## 6. Header pinout convention

Two headers per module, so jumper bundles look the same everywhere.

**J100 — rail header, 1×6, fixed pinout on every module** (omit pins a module
does not use, keep the positions):

| Pin | Net |
|---|---|
| 1 | `VBAT` |
| 2 | `GND` |
| 3 | `+3V3` |
| 4 | `GND` |
| 5 | `SENS_12V` |
| 6 | `GND` |

**J101 — signal header**, the module's §0.5 pins in contract order, `GND` at
both ends (return + keying):

| Module | J101 pinout (pin 1 → n) |
|---|---|
| `mod-power` | GND · `SENS_GATE` · `VBAT_SENSE` · `PWR_PG` · `I2C_SDA` · `I2C_SCL` · GND |
| `mod-mcu` | GND · `VBAT_SENSE` · `PWR_PG` · `SENS_PWR_EN` · `RS485_TX` · `RS485_RX` · `PUMP_EN` · `RESERVOIR_LOW_LEVEL` · `RESERVOIR_HIGH_LEVEL` · `I2C_SDA` · `I2C_SCL` · GND |
| `mod-rs485` | GND · `RS485_TX` · `RS485_RX` · `SENS_PWR_EN` · `SENS_GATE` · GND |
| `mod-pump` | GND · `PUMP_EN` · `I2C_SDA` · `I2C_SCL` · GND |
| `mod-level` | GND · `RESERVOIR_LOW_LEVEL` · `RESERVOIR_HIGH_LEVEL` · GND |
| `mod-i2c-env` | GND · `I2C_SDA` · `I2C_SCL` · GND |

`mod-mcu` keeps `U0TXD`/`U0RXD`/`EN`/`BOOT` internal (blocks 2+3 are on the same
board) and exposes J7 expansion + J6 JTAG as their own headers, as designed.

**Silkscreen every header pin with its net name.** This is the whole
self-documenting-bundle idea from `09-prototype-modules.md`.

## 7. Current — what must NOT go through a 2.54 mm header

2.54 mm headers are ~3 A per pin at best, and the design has three paths above
that:

| Path | Current | Route it as |
|---|---|---|
| Pump `VBAT` / `PUMP_P` / `PUMP_N` | ~4 A run, **~8 A max** | `mod-pump` gets its own screw terminal for `VBAT`+`GND`, wired directly to the power module's screw terminal — **never** via J100 |
| `VBAT` daisy-chain to other modules | < 0.5 A | J100 pin 1 is fine |
| `PANEL_RTN` / `PANEL_IN`/`OUT` | ~3 A | Screw terminals only (J8/J9 as designed); never on a header |

Rule of thumb for the module boards: **anything that can melt gets a terminal
block; anything that carries information gets a header.**

## 8. Layout rules per module (from the design notes)

Carry these across to stage B — they are the reason the notes exist:

- **`mod-power`:** minimal `C22`/`C32`–`U4`–`L20`–`C24` loop; keep `SW_NODE`
  away from the FB network `R21/R22/R28/C30` (`01` §1.2). `PANEL_RTN` ≥ 1 mm
  trace, isolated — the GND pour must not swallow it (`01` §1.5.1).
- **`mod-pump`:** tight switch loop `C5(−)`–`Q2` source on the same GND copper
  (`05` §5.2.1); `D1` freewheel right at the connector; Kelvin sense across
  `R1`; wide copper on `PUMP_P`/`PUMP_N`.
- **`mod-mcu`:** ESP32 antenna keep-out (WROOM-32UE is external-antenna, but
  respect the pad area); `C42` (1 µF) close to `EN`; USB island GND handling per
  `03` §3.4 — the island is separate on purpose, do not merge the pours.
- **`mod-rs485`:** `D4` (SM712) at the connector, before anything else;
  120 Ω `R3` at the far end of the pair.
- **`mod-level`:** `JP1`/`JP2` reachable with an iron after assembly.
- **All:** decoupling caps hard against their IC pin; test point (or an
  unpopulated 1-pin pad) on every rail — you will want a probe point.

## 9. Fabrication + parts ordering

**Boards.** Six designs at JLCPCB = six order lines + six shipping-weight items.
Cheaper and simpler: **panelize all six into one ≤100×100 mm board** with
mouse-bite tabs, ordered as a single design (5 pcs ≈ one cheap order → five
complete module sets). Trade-off: respinning one module means re-ordering the
whole panel — at this price that is acceptable, and a respin usually comes with
lessons for its neighbours anyway.

**Stencil.** Order a framework-less stencil for the panel, **0.1 mm (4 mil)** —
suits the finest pitch on the boards (CP2102N QFN-24 at 0.5 mm, MP2393 SOT583).
Ask for the stencil to match the panel, not the individual boards.

**Parts.** From `hardware/bom/WateringSystem-rev2-BOM-LCSC.md` — order every
C-number, **2× quantity on passives** (hand-assembly attrition), plus:

- 2.54 mm pin headers (male) and matching female sockets/jumper leads for J100/J101
- Solder paste (Sn63Pb37 or SAC305 — leaded is more forgiving on a hot plate),
  flux, braid, tweezers, 0.1 mm stencil (above)

**Already in stock — do not re-order:** Weidmüller 1715010000 ×4 (J2 battery,
J3 pump, J8/J9 panel). They are off-LCSC and were chosen because Paul already
had them.

**Solar telemetry group is POPULATED** (decided 2026-06-20, gate cleared
2026-08-10 — `01` §1.5): `U20` C49851, `R27` C553969, `C29` C14663 belong in
the LCSC order like any other part. The old "DNP by default" wording in the
design notes and BOM was stale and has been corrected.

## 10. Bring-up order and acceptance per module

Per `09-prototype-modules.md`, each step is powered by the previous one:

| # | Module | Accept when |
|---|---|---|
| 1 | `mod-power` | `+3V3` = 3.29 V ±2 %, `PWR_PG` HIGH, `SENS_12V` switches on `SENS_GATE`, `VBAT_SENSE` scales 14.6 V → 2.56 V, no part above hand-warm at load |
| 2 | `mod-mcu` | Auto-program works over USB-C (the `C42`=1 µF check, `03` §3.3.5); ESP-IDF hello-world flashes; `PWR_PG` reads HIGH on IO35 |
| 3 | `mod-rs485` | Modbus read of the NPK sensor; TX echo present as predicted (FW-4); IO17 pull-up masks the floating-RX case (FW-2) |
| 4 | `mod-pump` | FL-35 runs; `PUMP_EN` LOW at boot/reset/OTA (safety invariant); INA226 @ 0x40 current within ~10 % of a clamp meter |
| 5 | `mod-level` | XKC-Y26 reads active-LOW through the 2N7002 (FW-5); ≥ 500 ms settling honoured (FW-3) |
| 6 | `mod-i2c-env` | BME280 @ 0x77 plausible T/RH/P; all three I²C devices coexist on one bus |

These map 1:1 onto the deferred HIL checklists in `docs/checkpoints/hil-*.md`
and onto PR-14 bring-up.

## 11. When bring-up finds a problem

**Schematic-first, always.** Fix the design note → fix the shared block sheet →
both the module project and the integrated project pick it up (the module
project only needs `F8` again). Never patch a module board's layout to work
around a schematic error, and never edit a block sheet from inside a module
project to add prototype-only parts — those belong on the wrapper root.

Log every change in the block's design note with a date and the bring-up
observation that caused it, the same way the review findings are logged.

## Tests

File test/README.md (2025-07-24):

# RS485 Test Suite - WateringSystem

Detta är en samling testfiler för RS485 Modbus-kommunikation med jordsensorer, utvecklade under debugging-processen i juli 2025.

## Testfiler

### `test_level_shifter.cpp`
**Syfte:** Verifiera TXS0108E level shifter-funktionalitet
- Testar grundläggande GPIO-kommunikation genom level shifter
- Verifierar timing och signal-integritet
- Använd när du misstänker level shifter-problem

### `test_rs485_communication.cpp`
**Syfte:** Grundläggande RS485-kommunikationstest
- Enkel ping/pong-kommunikation
- Testar baud rate och timing
- Bra för initial debugging av RS485-anslutning

### `test_rs485_debug.cpp`
**Syfte:** Detaljerad debugging av RS485-protokoll
- Visar raw bytes som skickas/tas emot
- CRC-beräkning och validering
- Hex-output för protokollanalys

### `test_rs485_enhanced.cpp` ⭐ **REKOMMENDERAD**
**Syfte:** Komplett Modbus RTU-test med alla sensorfunktioner
- Läser alla register från jordsensorn (0x0000-0x000F)
- Interaktiv meny för specifika registerläsningar
- Auto-test sekvens för alla värden
- **Bevisad fungerande** - använd som referens för working implementation

## Historik och lärdomar

### Problemlösning Juli 2025
1. **Level shifter verification:** TXS0108E fungerar med 50µs delays
2. **Pin configuration fix:** GPIO 17=TX, GPIO 16=RX (var ombytta)
3. **Timing optimization:** Från 10µs till 50µs för pålitlig switching
4. **Protocol implementation:** Full Modbus RTU med CRC-validering

### Verifierade inställningar
```cpp
// Working configuration
#define TX_PIN 17
#define RX_PIN 16
#define DE_RE_PIN 25
#define RS485_DE_ASSERT_DELAY_US 50
#define RS485_DE_DEASSERT_DELAY_US 50
```

## Användning

### För att köra tester:
1. Ersätt innehållet i `src/main.cpp` med önskad testfil
2. Kompilera och ladda upp: `pio run -t upload`
3. Övervaka output: `pio device monitor -b 115200`

### För framtida debugging:
1. Börja med `test_rs485_enhanced.cpp` - den fungerar garanterat
2. Om den inte fungerar, kontrollera physical connections
3. Om den fungerar men huvudappen inte, jämför timing och pin-konfiguration
4. Använd `test_rs485_debug.cpp` för protokollanalys

### Return to main application:
```bash
git checkout src/main.cpp  # Återställ till huvudapplikation
pio run -t upload          # Ladda upp huvudappen
```

## Tekniska detaljer

### Modbus Register Map (NPK Soil Sensor)
| Register | Beskrivning | Enhet | Format |
|---|---|---|---|
| 0x0000 | Jordfuktighet | % | Unsigned 16-bit |
| 0x0001 | Jordtemperatur | 0.1°C | Signed 16-bit |
| 0x0002 | pH-värde | 0.1 pH | Unsigned 16-bit |
| 0x0003 | EC (Electrical Conductivity) | µS/cm | Unsigned 16-bit |
| 0x0004 | Kväve (N) | mg/kg | Unsigned 16-bit |
| 0x0005 | Fosfor (P) | mg/kg | Unsigned 16-bit |
| 0x0006 | Kalium (K) | mg/kg | Unsigned 16-bit |

### Hardware Setup
- ESP32-WROOM-32E
- TXS0108E bidirectional level shifter (3.3V ↔ 5V)
- MikroElektronika RS485 5 Click (MIKROE-4156)
- NPK Modbus soil sensor (device address 0x01)

---
*Skapad: Juli 2025*  
*Status: Verifierad fungerande med jordsensor NPK*

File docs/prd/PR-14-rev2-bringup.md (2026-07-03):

# PR-14: rev2-bringup

> Phase 6 — rev2 hardware. **Gated by SYNC 2 (boards delivered).**

## Goal

Bring up and validate the `BOARD_REV2` firmware on real rev2 hardware, then deploy to
the greenhouse and retire the Arduino unit after a two-week unattended soak.

## Scope

- Finalize the `BOARD_REV2` table in the board component against the as-built rev2
  board (pin numbers frozen at SYNC 1; correct any as-built deviations here).
- **Bring-up checklist (HIL on rev2 bench):**
  - Initial flash via **CP2102N** USB-C — first and last cable flash of the unit.
  - **THVD1426 auto-direction RS485 @ 9600 baud:** soil sensor reads with no DE pin;
    verify driver-release/idle behavior against datasheet timing (tHOLD vs 104 µs bit
    time at 9600 baud — open question from rev2 BOM) with scope on A/B; confirm bias
    resistors (R4 pull-up A, R5 pull-down B) give a defined idle state.
  - **INA226 (single device — rev2 has one pump channel, FR4 decision
    2026-06-10):** responds at its address (default 0x40, no collision with
    BME280 0x76/0x77); plausible 12 V bus voltage; current readings against a
    bench meter while the watering pump runs (high-side shunt R1).
  - **Single-pump node:** no reservoir pump output exists; verify the firmware
    (BOARD_HAS_RESERVOIR_PUMP=0) exposes exactly one pump in console/API and the
    reservoir level sensors report status without driving any refill logic.
    Greenhouse reservoir is refilled manually until the central reservoir unit
    exists (multi-zone, future PRD).
  - **Inverted level sensors:** XKC-Y26 through 2N7002 inverter ⇒ GPIO active LOW;
    wet/dry bench measurement confirms `BOARD_LEVEL_ACTIVE_LOW` mapping
    (counterpart of the PR-05 rev1 verification).
  - **JTAG smoke test:** attach debugger on header J6, halt/resume, read a variable —
    proves the debug path for future use.
  - BME280, pumps-off-at-boot, WiFi provisioning, web UI, watchdog reboot — rerun of
    the relevant parity run-sheet items on rev2.
- OTA proof on rev2: device installs an update from a GitHub Release (no cable).
- **Field deployment checklist** (deliverable, `docs/`): pre-deployment config,
  AP password rotation (open-question follow-up — old password is in public git
  history), physical install steps, rollback-to-Arduino-unit contingency, soak
  monitoring plan.
- Greenhouse deployment + **≥ 2 weeks unattended soak**; event log reviewed; Arduino
  unit retired afterwards (master PRD phase 6 exit criterion).

## Out of scope

- Hardware design changes (Paul's track; firmware-visible findings filed as issues).
  INA226 protection features, frontend modernization (separate PRDs). Migration of
  data from the Arduino unit (clean start, per master PRD).

## Functional requirements covered

- FR6 (INA226 validated on hardware); FR2/FR5 rev2 variants (DE-less RS485, inverted
  levels); final validation of all FRs in the field.

## Dependencies

- **SYNC 2** (rev2 boards delivered). PR-12 (parity proven), PR-13 (OTA, needed for
  cable-free operation in the field), PR-05 (drivers under test).

## Acceptance criteria

- [CI] Both targets still build; any rev2 pin-table fixes covered by the
  compile-time/host board-config checks from PR-02.
- [HIL] Entire bring-up checklist above ticked on the rev2 bench unit, with scope
  evidence for THVD1426 timing and meter evidence for INA226 current.
- [HIL] Rev2 unit OTA-updates itself from GitHub Releases.
- Field: rev2 unit runs the greenhouse **≥ 2 weeks without intervention**; event log
  shows no fail-safe surprises; Arduino unit decommissioned. **Project exit gate.**

## Estimated size

L

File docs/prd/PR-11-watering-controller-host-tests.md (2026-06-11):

# PR-11: watering-controller-host-tests

> Phase 4 — application logic

## Goal

Port `WateringController` (all watering logic, scheduling, reservoir state machine,
fail-safe behavior) to pure interface-based C++ and put **100 % of watering logic and
safety conditions under host tests running in CI** on the IDF linux target.

## Scope

- `WateringController` port from `src/WateringController.cpp`, consuming only
  interfaces (`IEnvironmentalSensor`, `ISoilSensor`, `IWaterPump`, `IDataStorage`,
  level sensors, injectable clock) — zero hardware includes, fully host-buildable.
- Behavior parity per `docs/parity-checklist.md` (the phase 0 ground truth), notably:
  - Moisture-threshold watering with configurable duration. **Minimum watering
    interval — RESOLVED by Paul, 2026-06-10: the ESP-IDF port MUST enforce it**,
    as a soak/absorption pause. This is a **DELIBERATE behavior change, not parity**:
    the Arduino code stores and persists the value but never enforces it (deliberate
    "NO minimum interval — if it's dry, water immediately!" comment,
    `WateringController.cpp:303`).
    - **Rationale (pulsed watering):** even bone-dry soil must be watered in bursts.
      Water needs time to absorb — poured continuously it pools on the surface while
      the moisture sensor lags, so the controller would keep filling. The automatic
      cycle is therefore: watering burst (configurable duration) → enforced soak
      pause (no automatic watering, even if the sensor still reads dry) →
      re-evaluate moisture → repeat until the high threshold is reached.
    - Both knobs (burst duration, soak pause) are runtime-configurable; good values
      are unknown yet and will be tuned empirically on the rig/in the greenhouse.
      The pause MUST be respected by automatic mode regardless of configuration
      source; manual mode is unaffected (operator override, as today).
    - Host tests MUST cover the soak gate: no automatic start during the pause,
      restart after expiry while still below threshold, and pause interaction with
      fail-safe stops (a safety stop must not be delayed by the gate).
  - Manual/automatic mode; manual operation bypasses sensor safety checks (parity).
    Manual runs capped at 300 s — **DELIBERATE behavior change, not parity**: the
    Arduino firmware runs manual/indefinite starts (legacy `/control` `start` with
    duration 0) uncapped (`docs/parity-checklist.md` §4).
  - **Fail-safe:** in automatic mode, invalid or stale soil data (Arduino staleness
    window: 30 s) stops the plant pump and blocks automatic watering (FR4).
  - Reservoir state machine on low/high level sensors: fill on low, stop on high,
    hard 300 s max fill runtime, sensor-implausibility handling (high without low).
    Active only on boards with a local refill pump (`BOARD_HAS_RESERVOIR_PUMP`,
    rev1 — FR4 decision 2026-06-10); on rev2 the level sensors feed status (and a
    future refill-request in the multi-zone PRD). The state machine is still fully
    host-tested (logic is board-independent; the flag gates the wiring).
  - Data logging cadence (Arduino default 5 min) into `IDataStorage`.
  - Time-not-set behavior (pre-SNTP) defined and tested.
- **Host test suite in CI** (IDF linux target + mocks from PR-02..06):
  every watering decision branch and every safety condition covered; CI gate fails
  the build on test failure. This is the master PRD success criterion "watering
  logic and safety conditions 100 % host-tested".
- On-target wiring: controller task replaces the direct pump/config plumbing from
  PR-09's interim mode; API mode switch now drives the controller.

## Out of scope

- Running the parity checklist on the rig (PR-12). New control features beyond
  parity. INA226-based protections (separate PRD).

## Functional requirements covered

- FR1 (controller port with preserved behavior); FR4 (completed: fail-safe stop on
  invalid sensor data in auto mode); FR5 (reservoir control logic); testability NFR.

## Dependencies

- PR-02..PR-05 (interfaces + mocks + drivers), PR-06 (config/storage), PR-08
  (time source, watchdog registration for the controller task).

## Acceptance criteria

- [CI] Host test suite green in CI on every push; coverage of the controller's
  decision/safety branches demonstrated (coverage report or branch checklist in PR).
- [CI] Both board targets still build with the controller task integrated.
- [HIL] Smoke on rig: automatic mode waters when moisture below threshold; pulling
  the RS485 cable in auto mode stops the pump within the staleness window.
- [HIL] Reservoir fill starts on low, stops on high, and aborts at 300 s if the high
  sensor never triggers.

## Estimated size

L

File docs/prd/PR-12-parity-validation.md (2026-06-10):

# PR-12: parity-validation

> Phase 4 — application logic (completes phase 4 exit criteria)

## Goal

Execute the full `docs/parity-checklist.md` against the rig (HIL) and close every gap,
so the ESP-IDF firmware is demonstrably feature-par with Arduino v2.3.

## Scope

- Dry-run pass by the implementer: walk the parity checklist against the merged
  firmware (PR-02..PR-11), mark items expected-pass / needs-fix / needs-rig.
- Fix all gaps found — bug fixes and small behavior corrections only; anything
  larger goes back to the owning PR's follow-up.
- Produce the **HIL checklist run-sheet** (concrete step-by-step protocol per
  checklist item: preconditions, action, expected observation) that Paul executes on
  the rig at checkpoint 3. Categories from the phase 0 checklist:
  - Watering logic: thresholds, min interval, duration, manual/auto.
  - Sensor validation + fail-safe pump stop (incl. stale-data window).
  - Reservoir state machine incl. 300 s max fill and FR5 polarity note
    (level-sensor polarity = *correct* behavior, explicitly not bug-for-bug parity;
    bench measurement from PR-05 is the reference).
  - All web routes (real route list extracted from Arduino code → `/api/v1/`
    equivalents mapping table).
  - Serial diagnostic commands (`rs485test`/`test`, `soil`/`sensor`, `help` parity).
  - WiFi reconnection and provisioning/AP behavior; NTP/local time.
  - Storage: config persistence, history logging, documented format divergences
    (clean start on rev2 — no data migration, per master PRD).
- Update `docs/parity-checklist.md` with ticked boxes, measured values, and dated
  sign-off; deviations (intentional, e.g. FR5 polarity fix) recorded with rationale.

## Out of scope

- New functionality. Performance work beyond parity. Rev2-specific behavior (PR-14).

## Functional requirements covered

- Verification pass over FR1–FR5, FR8–FR10, FR12–FR13 (master PRD success criterion:
  parity checklist 100 % ticked, including all fail-safe behaviors).

## Dependencies

- PR-09, PR-10, PR-11 (everything user-visible must be merged). Rig availability.

## Acceptance criteria

- [CI] Full pipeline (build both targets + host test suite) green on the final commit.
- [HIL] Parity checklist 100 % ticked on the rig by Paul, every fail-safe item
  demonstrated live (sensor unplug, reservoir overrun, watchdog, WiFi loss).
- Review: ticked checklist + deviation log approved — this is the phase 4 gate and
  the green light for phase 5 (OTA) field-readiness claims.

## Estimated size

M

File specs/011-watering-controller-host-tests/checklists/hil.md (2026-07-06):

# HIL Checklist: Watering Controller (011) — rev1 bench rig

**Purpose**: hardware-in-the-loop smoke of PR-11 at Checkpoint 3 (Paul, bench rig). The merge-gating
deliverable is the 100 % host-tested watering logic (289/0 in CI); this HIL is a confidence smoke that the
wired-up controller behaves on real hardware.
**Rig**: ESP32 devkit (rev1) provisioned with valid home-WiFi credentials (station mode, so `/api/v1/` binds
and the flag can be driven remotely); BME280 on I2C, RS485 soil sensor, plant + reservoir pumps, and the two
XKC-Y26 level sensors as wired for the previous features. A laptop/phone on the same LAN with `curl`, plus a
serial console (`ws>`, 115200) for the RS485 pull and event-log checks.
**Build**: rev1 target (`sdkconfig.board.rev1_devkit`), flash per `firmware/CLAUDE.md`. Confirm the serial
log shows `watering task started (... ms cadence)` and `sensor task started` after boot.
**Reference**: acceptance criteria `docs/prd/PR-11-*.md`; spec FR-001..FR-017 (esp. FR-003 soak, FR-005/006
fail-safe, FR-012a cooldown, FR-014 logging, FR-017 isolation); `quickstart.md` §HIL; `data-model.md`
decision tables; parity `docs/parity-checklist.md`.
**Setup**: note the device IP (console `wifi` / router / `GET /api/v1/status`). Export it, e.g.
`export DEV=192.168.1.50`, and prefix curls with `http://$DEV/api/v1/...`. Set short thresholds/intervals via
`POST /api/v1/config` (or the `config` console command) so a full cycle is observable in minutes:
a low soak (`minWateringIntervalS`), a short burst (`wateringDurationS`), a low sensor interval
(`sensorReadIntervalMs`), and low/high moisture thresholds bracketing the current soil reading.

**Note on cadence**: the controller ticks at `sensorReadIntervalMs` (floored at 1 s), so a decision may lag a
config/soil change by up to one interval — allow for that when timing the observations below.

## A. Live soil reader (US3, quickstart §HIL #5)

- [ ] A1. `curl http://$DEV/api/v1/sensors` now shows `soil.valid:true` with fresh, plausible values
      (moisture/temp/pH/EC and NPK when the sensor reports them) — the periodic reader is running (this is
      the PR-09 limitation being lifted)
- [ ] A2. The soil values refresh over time (poll twice ~2 intervals apart while touching the probe / moving
      it between dry and wet media — the reading tracks)
- [ ] A3. `soil.valid` returns to `false` (last-good placeholders) after the RS485 pull in D1, then recovers
      to `true` once reconnected

## B. Automatic pulsed watering + soak (US1, quickstart §HIL #1, FR-002/003)

- [ ] B1. In automatic mode (`GET /api/v1/status` → `mode:automatic`; set via `POST /api/v1/config`
      `{"wateringEnabled":true}`) with the soil below the low threshold (dry probe), the plant pump starts a
      burst of ~`wateringDurationS`
- [ ] B2. After the burst ends the pump does NOT immediately restart even while the soil still reads dry —
      it waits out the soak pause (`minWateringIntervalS`) measured from the burst END, then re-waters
- [ ] B3. When the soil rises to ≥ the high threshold (wet the probe), a running burst stops and no new burst
      starts
- [ ] B4. Change `wateringDurationS` / thresholds via `POST /api/v1/config` mid-run → the next tick/burst
      picks up the new values (runtime-tunable, no reflash)

## C. Fail-safe precedence (US1, quickstart §HIL #2, FR-005/006)

- [ ] C1. With the plant pump mid-burst in automatic mode, pull the RS485 soil cable → the pump stops within
      the staleness window (~30 s), and `/api/v1/sensors` shows `soil.valid:false`
- [ ] C2. A `reset=`/`failsafe` entry appears in `GET /api/v1/events` (or console `storage events`) with a
      detail like `soil-stale` / `soil-unavailable`
- [ ] C3. **Soak does not delay a safety stop**: trigger the pull DURING an active soak pause (pump just
      stopped, waiting to re-water) — confirm the fail-safe still fires (no watering resumes) rather than
      waiting for the soak to elapse
- [ ] C4. Reconnect the cable → after a fresh valid read the controller resumes normal automatic behavior
      (no reboot occurred — check uptime in `/status`)

## D. Manual override (US3, quickstart §HIL #3, FR-007..010)

- [ ] D1. With the RS485 cable pulled (soil failing), a manual run still executes:
      `POST /api/v1/pumps/plant {"action":"run","durationS":15}` → the plant pump runs despite the sensor
      failure (manual bypasses fail-safe)
- [ ] D2. A manual `durationS` above 300 is capped at 300 s; the pump never runs past the hard cap
- [ ] D3. `POST {"action":"stop"}` stops the manual run and clears the override; switching back to automatic
      (`wateringEnabled:true`) with a valid dry sensor then resumes automatic bursts
- [ ] D4. In manual mode (`wateringEnabled:false`) the controller takes NO automatic action (no bursts start
      on their own)

## E. Reservoir auto-fill (US2, quickstart §HIL #4, FR-012/012a)

- [ ] E1. With both level marks dry (low-dry + high-dry) in automatic mode, the reservoir fill pump starts
- [ ] E2. When the high mark goes wet, the fill pump stops immediately
- [ ] E3. **Max-fill abort**: with the high mark forced to stay dry (disconnected / empty source), the fill
      pump aborts at the 300 s cap rather than running forever
- [ ] E4. **Post-abort cooldown**: after the E3 abort, no new automatic fill starts for ~`kReservoirRefill
      CooldownMs` (~60 s) even though low still reads dry; after the cooldown a fill re-attempts. A normal
      high-wet stop (E2) does NOT impose the cooldown; a manual fill
      (`POST /api/v1/pumps/reservoir {"action":"run",...}`) starts immediately regardless of cooldown
- [ ] E5. A stuck/settling level mark (`not_yet_valid`) never triggers a fill (invalid ≠ dry)

## F. Data logging (US3, FR-014)

- [ ] F1. After the first SNTP sync (`/status` → time `synced:true`), `GET /api/v1/history?metric=env_
      temperature&range=1h` returns a growing series at roughly `dataLogIntervalMs` cadence
- [ ] F2. Soil metrics log too (`metric=soil_moisture`); `soil_humidity` is intentionally absent (identical
      to `soil_moisture`); NPK metrics appear only when the sensor reports them (≥ 0)
- [ ] F3. Before the first sync (power-cycle, no network) no bogus 1970-epoch rows are written (query shows
      nothing logged until the clock is set)

## G. Isolation (FR-017, quickstart §HIL #6)

- [ ] G1. During an active automatic watering cycle, drop WiFi (power off the AP / `wifi-clear` is too
      destructive — just move out of range or disable the AP) → the plant/reservoir behavior is UNAFFECTED
      (bursts, stops, soak continue on schedule)
- [ ] G2. Flood the API with requests (a `curl` loop against `/api/v1/sensors`) while a burst runs → watering
      timing is unaffected; the 10 Hz pump-timing stays crisp (pump stops at the burst duration, not late)

## H. RS485 race fix (T016)

- [ ] H1. While the periodic reader is active (watering task running), issue `ws> rs485test` repeatedly on
      the console → it returns clean probe results + statistics with no bus corruption, garbled frames, or
      lock-ups, and `/api/v1/sensors` soil readings stay coherent throughout (shared-mutex serialization)

## Definition of done

- [ ] HIL smoke executed on the rev1 rig at Checkpoint 3, OR deferred with rationale if no rig time is
      available (record in the deferred-HIL register alongside the earlier features' deferrals).
- [ ] Any anomaly filed and triaged; a fail-safe or isolation miss (Section C or G) blocks merge, the rest
      are logged for follow-up.

**Deferral note**: like PR-04/07/08/09, if the rig is unavailable this checklist is deferred (not skipped).
The merge is gated by the host suite (289/0) + both board builds; the HIL is the on-hardware confidence pass
Paul runs when the bench is free.

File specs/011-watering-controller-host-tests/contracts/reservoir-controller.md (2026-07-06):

# Contract: `ReservoirController` (pure state machine)

`firmware/components/control/include/control/ReservoirController.h` + `src/ReservoirController.cpp`. Pure,
board-independent; host-tested regardless of board (the `BOARD_HAS_RESERVOIR_PUMP` flag gates only
construction/wiring in `app_main`, never the logic — FR-013).

## Construction
`ReservoirController(ILevelSensor& lowMark, ILevelSensor& highMark, IWaterPump& fillPump,
ITimeProvider& clock, EventLogger& events)` (or the `Locked*` wrappers). Fill duration + the 300 s cap come
from the pump (`runFor` / max-runtime).

## Public surface
| Member | Contract |
|---|---|
| `void tick(bool enabled, bool autoLevelControl)` | `fillPump.update()` (cap) → running-safety (stop on high / cap) → if enabled+auto+not-running, evaluate the truth table. |
| `bool startManualFill(int durationS)` | manual fill (refuse if already full = high wet); capped at 300 s. |
| `void stop()` | `fillPump.stop()`. |

## Truth table (auto; enabled, auto-level, pump not running)
| low mark | high mark | action |
|---|---|---|
| invalid, or high invalid | — | **no action** (invalid never = dry — ILevelSensor contract) |
| wet | wet | full → ensure stopped |
| wet | dry | sufficient → no action |
| dry | dry | **start fill** (`fillPump.runFor(fill)`) |
| dry | wet | physically implausible → **no action** |

## Running safety (manual + auto)
- high mark reads wet → `stop()` immediately.
- `fillPump.update()` aborts at the 300 s hard max fill.

## Post-abort cooldown (resolved by Paul 2026-07-05 — deliberate divergence from parity)
After a fill ends by the max-runtime abort (`StopReason::MaxRuntimeForced`), record the abort time and do
NOT start another automatic fill until a cooldown (`kReservoirRefillCooldownMs`, a documented constant,
default ~60 s, tunable) has elapsed — even if the water still reads low. This prevents a stuck high sensor
or an empty source from producing an endless 300 s pump cycle. A normal stop (high-wet reached) does NOT
trigger the cooldown. Manual fill is unaffected.

## Feature gate (FR-013)
`!enabled` (or the board lacks the pump) → `fillPump.stop()` (force off) + skip all logic.

## Host-test targets (SC-004)
Every truth-table row incl. both invalid-sensor and implausible → no-action; start-on-low-dry;
stop-on-high-wet while running; max-fill abort at 300 s; disabled forces off; after-abort re-evaluation is
safe (no tight re-slam). Driven over two `MockLevelSensor` + `MockWaterPump` (real `WaterPump` over
`FakeTimeProvider`).

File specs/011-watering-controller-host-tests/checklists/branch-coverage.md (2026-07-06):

# Branch-coverage Checklist: Watering Controller (011)

**Purpose**: prove every decision + safety branch of the pure controllers is exercised by a host test (the
merge-gating deliverable — 100 % host-tested watering logic). Each row maps a branch from `data-model.md` /
the contracts to the covering test. All boxes are checked only because the full host suite is green.

**Verification run (this branch, `011-watering-controller-host-tests`):**

- [x] Full host suite green: **293 Tests, 0 Failures, 0 Ignored** (`pump_host_tests.elf`, exit 0)
      — of which 26 in `test_watering_controller.cpp` + 15 in `test_reservoir.cpp` are new for feature 011
      (incl. the CP3-round additions T-A/T-B/T-C + the NPK and env-read-failure branches).
- [x] rev1 build green (`sdkconfig.board.rev1_devkit`) — `REV1_RC=0`, app 1037.3 KiB / 1536 KiB slot (32.5 %
      margin).
- [x] rev2 build green (`sdkconfig.board.rev2`) — `REV2_RC=0`, app 1039.4 KiB / 1536 KiB slot (32.3 % margin).
- [x] No new managed dependencies; `dependencies.lock` + esp-modbus (`==2.1.2`) unchanged (T018).

## WateringController — decision branches

- [x] Start burst: enabled + not running + moisture ≤ low + soak elapsed → `runFor(burst)`
      — `test_starts_burst_when_dry_and_enabled`
- [x] No automatic action when watering disabled (manual/suspended mode) — `test_no_start_when_disabled`
- [x] Stop at target: running + moisture ≥ high → `stop()`, arm soak from burst end
      — `test_stops_at_high_threshold`
- [x] Soak gate (FR-003): after a burst ends, no new burst until the pause elapses even while dry; then
      restart — `test_soak_pause_blocks_then_allows_restart`
- [x] Soak origin armed on the HIGH-THRESHOLD stop path (`lastBurstEndMs_` set at line 110) — T-A
      — `test_soak_origin_armed_on_high_threshold_stop`
- [x] Config thresholds/durations re-read each tick (runtime-tunable) — `test_config_change_picked_up_next_tick`
- [x] Low/high thresholds are inclusive boundaries — `test_boundaries_low_and_high_inclusive`

## WateringController — read gating

- [x] No action before the first successful read (gate on read, not placeholder) — FR-004
      — `test_no_action_before_first_successful_read`
- [x] Transient failed read while last-good is fresh → wait, no fail-safe — `test_gate_on_transient_failed_read`

## WateringController — fail-safe (safety branches, FR-005/006)

- [x] Soil unavailable while running → immediate stop + `logFailsafe` — `test_failsafe_unavailable_stops_running_pump`
- [x] Soil stale (> 30 000 ms / never) while running → stop + log — `test_failsafe_stale_stops_running_pump`
- [x] Moisture out of 0..100 → stop + log — `test_failsafe_invalid_moisture_stops_running_pump`
- [x] **Fail-safe is NOT delayed by the soak gate** (checked before it) — `test_failsafe_not_delayed_by_soak`
- [x] Fail-safe during a pending soak pause takes no watering action — `test_failsafe_during_pending_soak_takes_no_action`
- [x] Graceful degradation: constructs + never waters when a sensor failed init — `test_graceful_degradation_never_waters`

## WateringController — manual override (FR-007..010)

- [x] Manual run bypasses fail-safe (runs despite sensor failure) — `test_manual_run_bypasses_sensor_failure`
- [x] Manual duration capped at 300 s — `test_manual_run_capped_at_300s`
- [x] Manual duration lower-clamped to 1 s — `test_manual_run_lower_clamp`
- [x] Auto-started run is NOT flagged manual (fail-safe still applies) — `test_auto_run_is_not_flagged_manual`
- [x] `stop()` clears the override (automatic resumes) — `test_stop_clears_manual_override`

## WateringController — data logging (FR-014)

- [x] Logs at the data-log cadence (interval gate) — `test_data_log_cadence`
- [x] Epoch timestamp + NPK-only-when-≥0 filter (nitrogen<0) — `test_data_log_epoch_and_npk_filter`
- [x] NPK ≥0 filter, phosphorus + potassium negative branches — `test_data_log_npk_phosphorus_potassium_negative`
- [x] Exactly-10-metric cap with NO silent drop (drop-sensitive: `rejectedWrites == 0`) — T-C, asserted in
      `test_data_log_cadence`
- [x] Gated on `isTimeSet()` (no bogus 1970) — `test_data_log_gated_on_time_set`
- [x] Telemetry logs even on the fail-safe path (env still logged, soil skipped) — `test_data_log_runs_on_failsafe_path`
- [x] Env read failure → env metrics skipped, soil still logged — `test_data_log_env_read_failure`

## WateringController — soil access (M2, post-CP3)

- [x] `tick()` reads once then consumes ONE `snapshot()` (no second blocking `isAvailable()` probe);
      availability = ever-read-ok — exercised across the fail-safe reason tests (`lastFailsafeReason()`
      asserts `soil-unavailable` vs `soil-stale`)

## ReservoirController — truth table (FR-012/013)

- [x] Low invalid → no action (invalid ≠ dry) — `test_invalid_low_no_action`
- [x] High invalid → no action — `test_invalid_high_no_action`
- [x] Both invalid → no action — `test_both_invalid_no_action`
- [x] wet + wet (full) → ensure stopped — `test_full_wet_wet_ensures_stopped`
- [x] wet + dry (sufficient) → no action — `test_sufficient_wet_dry_no_action`
- [x] dry + dry → start fill — `test_low_dry_dry_starts_fill`
- [x] dry + wet (implausible) → no action — `test_implausible_low_dry_high_wet_no_action`

## ReservoirController — running safety + cooldown (FR-012a)

- [x] Stop on high-wet while running — `test_stop_on_high_wet_while_running`
- [x] Max-fill abort at the 300 s cap (MaxRuntimeForced) — `test_max_fill_abort_at_cap`
- [x] Post-abort cooldown blocks a new auto fill, then allows it — `test_cooldown_blocks_then_allows_auto_refill`
- [x] A normal high-wet stop does NOT arm the cooldown — `test_normal_high_wet_stop_does_not_arm_cooldown`
- [x] Manual fill bypasses the cooldown — `test_manual_fill_bypasses_cooldown`
- [x] Manual fill refused when already full (high wet) — `test_manual_fill_refused_when_full`
- [x] Auto-level-control OFF while enabled suppresses auto fill; manual fill still works — T-B
      — `test_auto_level_off_suppresses_fill_but_manual_works`
- [x] Feature disabled forces the pump off and skips all logic — `test_feature_disabled_forces_off_and_skips_logic`

## Not host-covered (target-only / HIL)

These branches are on-target integration, verified by the board builds + the HIL checklist, not the host suite:

- [ ] Periodic soil reader refreshes the `/sensors` cache (controller-as-reader) — HIL §A
- [ ] Watering task watchdog subscribe/feed — HIL (implicit: no TASK_WDT reboot during a cycle)
- [ ] `LockedModbusClient` serializes rs485test with the reader (no bus overlap) — HIL §H
- [ ] Isolation: watering unaffected by WiFi/HTTP load — HIL §G

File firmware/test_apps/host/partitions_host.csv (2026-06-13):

# Partition table for the host test app (linux preview target).
#
# The linux esp_partition emulation builds its file-backed flash from this
# table, which lets the REAL nvs_flash implementation run in host tests
# (research.md D3; reference pattern: IDF components/nvs_flash/host_test).
# Only `nvs` is used; phy_init/factory keep the layout valid.
# Name,    Type, SubType, Offset,  Size,   Flags
nvs,       data, nvs,     0x9000,  0x6000,
phy_init,  data, phy,     0xf000,  0x1000,
factory,   app,  factory, 0x10000, 1M,

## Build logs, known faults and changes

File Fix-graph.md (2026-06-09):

# Graf-problem: Analys och Lösningar

**Datum:** 2025-01-02  
**Status:** Identifierad, ej åtgärdad  
**Analyserad av:** Claude Code via Playwright

## Problemsammanfattning

Webbgränssnittets graf i "Historical Data"-sektionen är tom och visar inga datapunkter, trots att realtidsdata fungerar korrekt.

## Identifierade Problem

### 1. Reading-dropdown populeras inte vid sidladdning
**Fil:** `data/script.js:865-886`  
**Problem:** `updateChartOptions()` körs aldrig automatiskt när sidan laddas.

**Symptom:**
- Sensor dropdown: "Environmental" (funkar)
- Reading dropdown: Tom vid sidladdning
- Time Range dropdown: "Last 24 hours" (funkar)

**Orsak:** Funktionen körs bara när användaren manuellt ändrar sensor-dropdown (rad 227 event listener).

**Lösning:** 
```javascript
// I initApp() funktionen, efter initChart():
updateChartOptions(); // Lägg till denna rad
```

### 2. Tom historisk data från servern
**Endpoint:** `/history?sensor=env&reading=temperature&range=24h`

**Aktuell respons:**
```json
{
  "sensorId": "env",
  "readingType": "temperature", 
  "startTime": 0,
  "endTime": 1756833826,
  "readings": []  // <-- TOM ARRAY
}
```

**Problem:** Inga historiska mätningar finns lagrade i systemet.

### 3. Dataformat-mismatch mellan klient och server
**Fil:** `data/script.js:930-931`

**Klientkod förväntar sig:**
```javascript
if (!appState.chart || !data || !data.timestamps || !data.values) {
    return;
}
// ...
appState.chart.data.labels = data.timestamps.map(t => new Date(t));
appState.chart.data.datasets[0].data = data.values;
```

**Server returnerar:**
```json
{
  "readings": []  // Inte timestamps + values
}
```

## Kritisk Undersökning Behövs

### 🔍 PUNKT 3: Datalagring - Hur är det tänkt att fungera?

**VIKTIGT:** Undersök hur historisk sensordata ska lagras och hämtas:

1. **Backend-implementation:**
   - Sök i ESP32-koden efter `/history` endpoint implementation
   - Kontrollera om data lagras i LittleFS eller bara i minnet
   - Verifiera dataformat som skickas från server

2. **Databasfrågor att besvara:**
   - Var lagras historisk sensordata? (LittleFS files, JSON arrays i minnet?)
   - Hur ofta sparas mätningar? (varje 5s som realtidsdata, eller mindre frekvent?)
   - Vilken datastruktur används för lagring?
   - Finns det en retention policy (rensning av gammal data)?

3. **Filer att undersöka:**
   - `src/` katalogen för `/history` endpoint handler
   - `storage/` klasser för datalagring
   - Eventuella config-filer för datalagring

4. **Test att köra:**
   - Låt systemet köra i några timmar
   - Kontrollera om `/history` endpoint börjar returnera data
   - Verifiera att dataformatet matchar client-förväntningarna

## Tekniska Fixes Behövs

### Fix 1: Automatisk dropdown-populering
```javascript
// I data/script.js, function initApp() runt rad 146
// Efter: initChart();
// Lägg till:
updateChartOptions();
```

### Fix 2: Dataformat-kompatibilitet
Antingen:
- **A) Ändra server** för att returnera `{timestamps: [], values: []}` 
- **B) Ändra klient** för att hantera `{readings: []}` format

### Fix 3: Datalagring (efter undersökning)
- Implementera historisk datalagring om den saknas
- Konfigurera lämplig sampling-frekvens för grafer
- Säkerställ att gammal data rensas för att spara utrymme

## Testplan för Lösning

1. **Steg 1:** Fix dropdown-problem och testa manuellt
2. **Steg 2:** Undersök backend-datalagring grundligt  
3. **Steg 3:** Åtgärda dataformat-mismatch
4. **Steg 4:** Implementera/fixa datalagring om nödvändigt
5. **Steg 5:** E2E-test med Playwright för att verifiera graf fungerar

## Observationer från Analys

- **Realtidsdata fungerar perfekt:** BME280 (temp, humidity, pressure) uppdateras var 5:e sekund
- **Jordsensor problem:** "Soil sensor read failed: 3" (separat problem, ej relaterat till graf)
- **Chart.js implementation:** Korrekt implementerad med mörk tema-stöd
- **API endpoints:** `/sensors` och `/status` fungerar, `/history` returnerar tom data

## Referenser

- **Analyserad kod:** `data/script.js:759-986` (Chart implementation)
- **Test endpoint:** `http://192.168.1.123/history?sensor=env&reading=temperature&range=24h`
- **Console logs:** Kontinuerliga "Soil sensor read failed: 3" meddelanden
- **Webbläsare:** Playwright automation i Chrome/Chromium

---
*Detta dokument ska användas som arbetsmaterial när tid finns för att implementera graf-fixes.*

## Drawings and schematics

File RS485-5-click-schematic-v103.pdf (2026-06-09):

# RS485 5 Click schematic v103

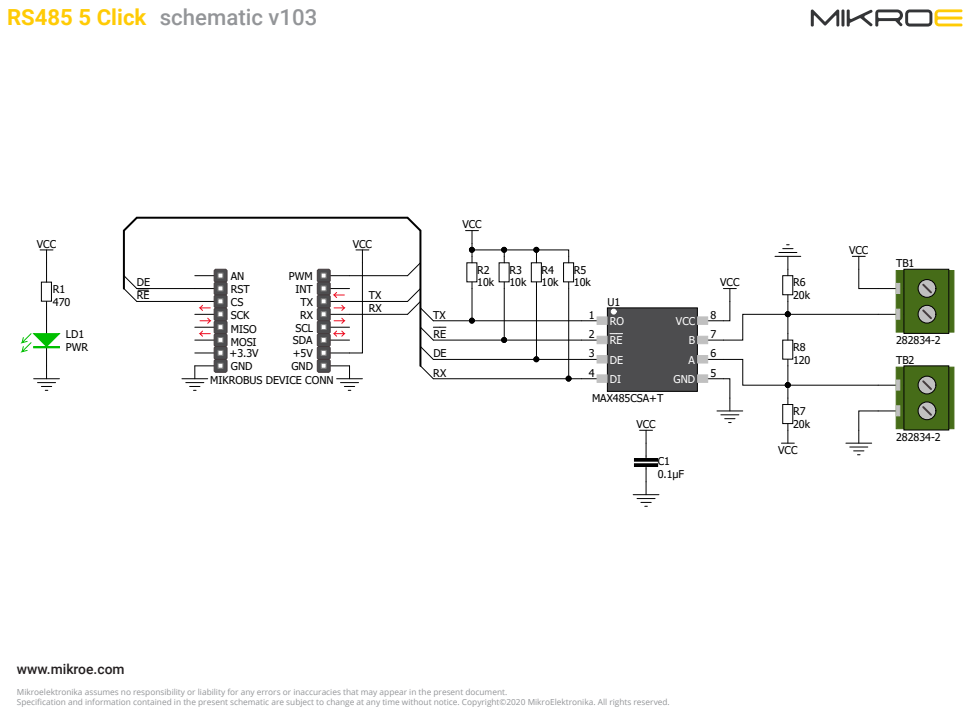
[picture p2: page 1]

Mikroelektronika assumes no responsibility or liability for any errors or inaccuracies that may appear in the present document.
Specification and information contained in the present schematic are subject to change at any time without notice. Copyright©2020 MikroElektronika. All rights reserved.

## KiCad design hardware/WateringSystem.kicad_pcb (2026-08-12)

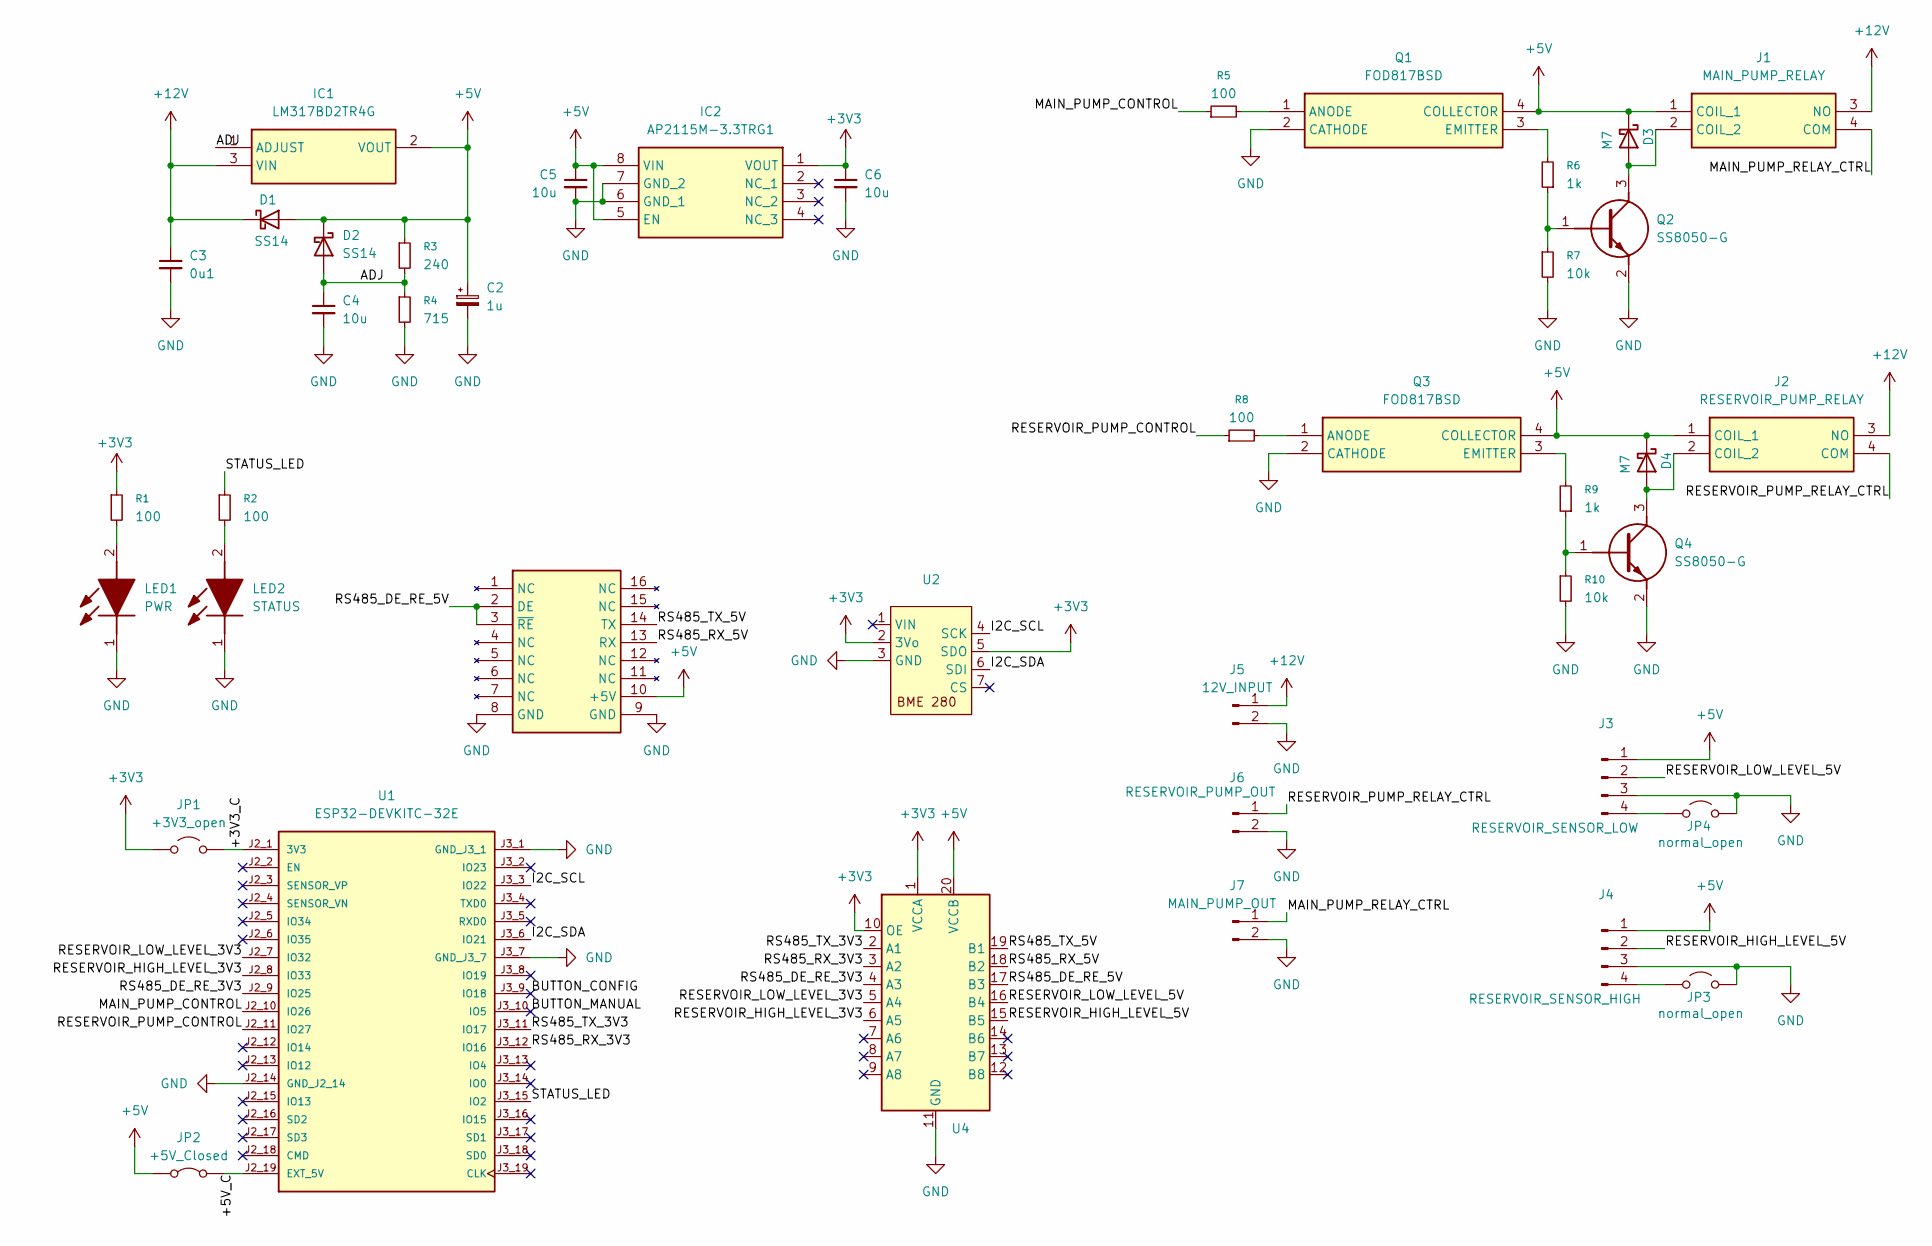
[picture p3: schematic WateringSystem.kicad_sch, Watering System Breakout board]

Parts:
Breakoutboard1: MAX485ESA+T_breakout
C2: 1u; CP_EIA-2012-12_Kemet-R
C3: 0u1; C_0805_2012Metric
C4, C5, C6: 10u; C_0805_2012Metric
D1, D2: SS14; D_SMA
D3, D4: M7; D_SMA
IC1: LM317BD2TR4G; Mouser Part Number 863-LM317BD2TR4G
IC2: AP2115M-3.3TRG1; SOIC127P600X175-8N; Mouser Part Number 621-AP2115M-3.3TRG1
J1: MAIN_PUMP_RELAY; 120715561; Mouser Part Number 655-1-2071556-1
J2: RESERVOIR_PUMP_RELAY; 120715561; Mouser Part Number 655-1-2071556-1
J3: RESERVOIR_SENSOR_LOW; JST_XH_B4B-XH-A_1x04_P2.50mm_Vertical
J4: RESERVOIR_SENSOR_HIGH; JST_XH_B4B-XH-A_1x04_P2.50mm_Vertical
J5: 12V_INPUT; WEID_1715010000
J6: RESERVOIR_PUMP_OUT; WEID_1715010000
J7: MAIN_PUMP_OUT; WEID_1715010000
JP1: +3V3_open; SolderJumper-2_P1.3mm_Open_RoundedPad1.0x1.5mm
JP2: +5V_Closed; SolderJumper-2_P1.3mm_Bridged_RoundedPad1.0x1.5mm
JP3, JP4: normal_open; SolderJumper-2_P1.3mm_Open_RoundedPad1.0x1.5mm
LED1: PWR; 150080SS75000; Mouser Part Number 710-150080SS75000
LED2: STATUS; LEDC2012X80N; Mouser Part Number 710-150080VS75000
Q1, Q3: FOD817BSD; SOP254P1016X385-4N; Mouser Part Number 512-FOD817BSD
Q2, Q4: SS8050-G; SOT95P240X115-3N; Mouser Part Number 750-SS8050-G
R1, R2, R5, R8: 100; R_0805_2012Metric
R3: 240; R_0805_2012Metric
R4: 715; R_0805_2012Metric
R6, R9: 1k; R_0805_2012Metric
R7, R10: 10k; R_0805_2012Metric
U1: ESP32-DEVKITC-32E; ESP32-DEVKITC-32E_MODULE_ESP32-DEVKITC-32E-for headers; PARTREV 1.4; DigiKey_Part_Number 1965-ESP32-DEVKITC-32E-ND
U2: BME_280_qt_version
U4: TXS10108E_breakout

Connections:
+3V3: C6.1, IC2.1 (VOUT), JP1.1 (A), R1.1, U2.2 (3Vo), U2.5 (SDO), U4.1 (VCCA), U4.10 (OE)
+5V: Breakoutboard1.10 (+5V), C2.1, C5.1, D1.2 (A), D2.1 (K), D3.1 (K), D4.1 (K), IC1.2 (VOUT), IC2.5 (EN), IC2.8 (VIN), J1.1 (COIL_1), J2.1 (COIL_1), J3.1, J4.1, JP2.1 (A), Q1.4 (COLLECTOR), Q3.4 (COLLECTOR), R3.1, U4.20 (VCCB)
+12V: C3.1, D1.1 (K), IC1.3 (VIN), J1.3 (NO), J2.3 (NO), J5.1
/+3V3_C: JP1.2 (B), U1.J2_1 (3V3)
/+5V_C: JP2.2 (B), U1.J2_19 (EXT_5V)
/ADJ: C4.1, D2.2 (A), IC1.1 (ADJUST), R3.2, R4.1
/BUTTON_CONFIG: U1.J3_9 (IO18)
/BUTTON_MANUAL: U1.J3_10 (IO5)
/I2C_SCL: U1.J3_3 (IO22), U2.4 (SCK)
/I2C_SDA: U1.J3_6 (IO21), U2.6 (SDI)
/MAIN_PUMP_CONTROL: R5.1, U1.J2_10 (IO26)
/MAIN_PUMP_RELAY_CTRL: J1.4 (COM), J7.1
/RESERVOIR_HIGH_LEVEL_3V3: U1.J2_8 (IO33), U4.6 (A5)
/RESERVOIR_HIGH_LEVEL_5V: J4.2, U4.15 (B5)
/RESERVOIR_LOW_LEVEL_3V3: U1.J2_7 (IO32), U4.5 (A4)
/RESERVOIR_LOW_LEVEL_5V: J3.2, U4.16 (B4)
/RESERVOIR_PUMP_CONTROL: R8.1, U1.J2_11 (IO27)
/RESERVOIR_PUMP_RELAY_CTRL: J2.4 (COM), J6.1
/RS485_DE_RE_3V3: U1.J2_9 (IO25), U4.4 (A3)
/RS485_DE_RE_5V: Breakoutboard1.2 (DE), Breakoutboard1.3 (~RE), U4.17 (B3)
/RS485_RX_3V3: U1.J3_12 (IO16), U4.3 (A2)
/RS485_RX_5V: Breakoutboard1.13 (RX), U4.18 (B2)
/RS485_TX_3V3: U1.J3_11 (IO17), U4.2 (A1)
/RS485_TX_5V: Breakoutboard1.14 (TX), U4.19 (B1)
/STATUS_LED: R2.1, U1.J3_15 (IO2)
GND: Breakoutboard1.8 (GND), Breakoutboard1.9 (GND), C2.2, C3.2, C4.2, C5.2, C6.2, IC2.6 (GND_1), IC2.7 (GND_2), J3.3, J4.3, J5.2, J6.2, J7.2, JP3.2 (B), JP4.2 (B), LED1.1 (K), LED2.1 (K), Q1.2 (CATHODE), Q2.2 (E), Q3.2 (CATHODE), Q4.2 (E), R4.2, R7.2, R10.2, U1.J2_14 (GND_J2_14), U1.J3_1 (GND_J3_1), U1.J3_7 (GND_J3_7), U2.3 (GND), U4.11 (GND)
unnamed: D3.2 (A), J1.2 (COIL_2), Q2.3 (C)
unnamed: D4.2 (A), J2.2 (COIL_2), Q4.3 (C)
unnamed: J3.4, JP4.1 (A)
unnamed: J4.4, JP3.1 (A)
unnamed: LED1.2 (A), R1.2
unnamed: LED2.2 (A), R2.2
unnamed: Q1.1 (ANODE), R5.2
unnamed: Q1.3 (EMITTER), R6.2
unnamed: Q2.1 (B), R6.1, R7.1
unnamed: Q3.1 (ANODE), R8.2
unnamed: Q3.3 (EMITTER), R9.2
unnamed: Q4.1 (B), R9.1, R10.1

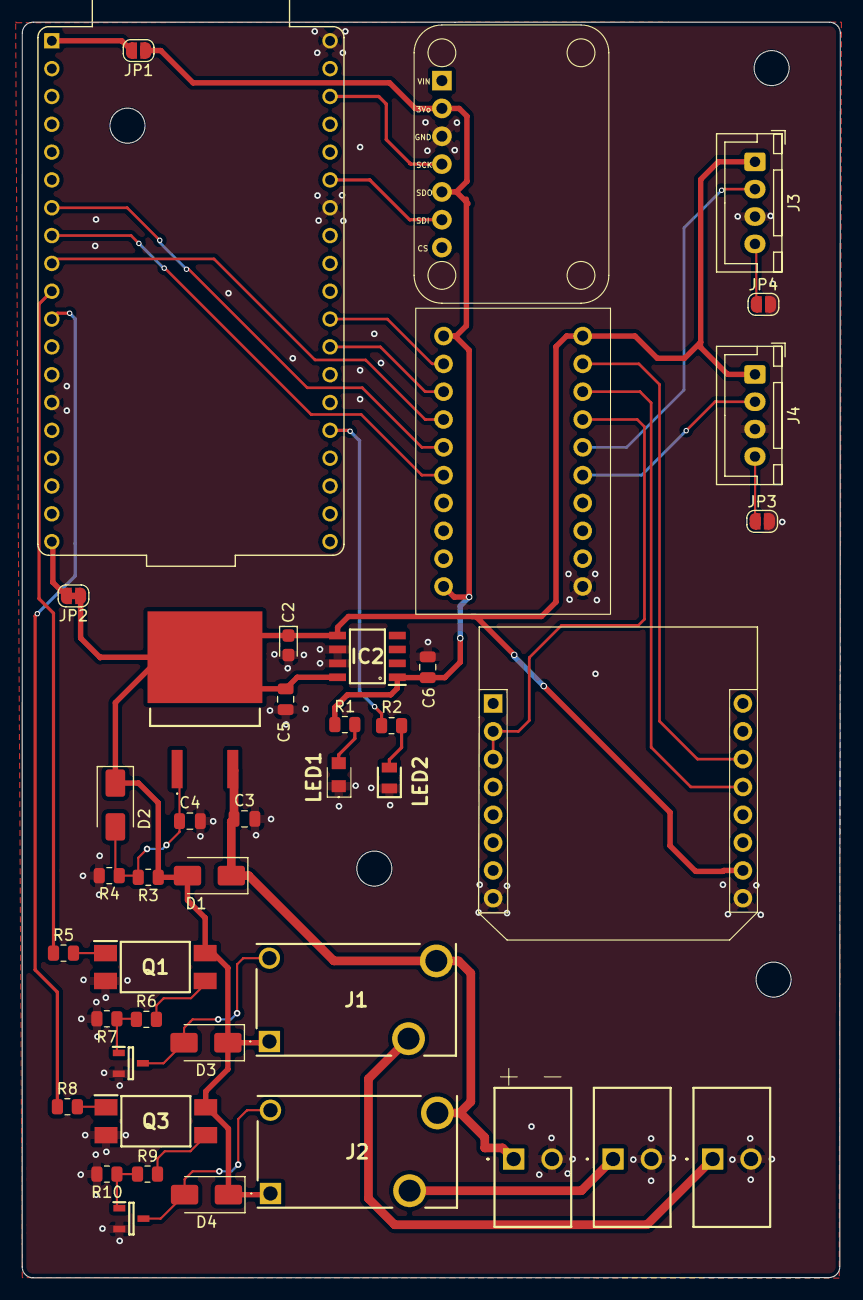
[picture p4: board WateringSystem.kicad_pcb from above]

Board: 4 copper layers, 74.7 x 114.6 mm, 42 parts (0 on the bottom side), 36 nets.

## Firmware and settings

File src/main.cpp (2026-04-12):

// SPDX-FileCopyrightText: 2025 Cryptotomte
// SPDX-License-Identifier: AGPL-3.0-or-later
/**
 * @file main.cpp
 * @brief Main application for the WateringSystem
 * @author Paul Waserbrot
 * @date 2025-04-15
 */

#include <Arduino.h>
#include <WiFi.h>
#include <time.h>
#include <Wire.h>
#include <ArduinoJson.h>
#include <LittleFS.h>
#include "soc/soc.h"
#include "soc/rtc_cntl_reg.h"

// Include our components
#include "WateringController.h"
#include "sensors/BME280Sensor.h"
#include "sensors/ModbusSoilSensor.h"
#include "communication/SP3485ModbusClient.h"
#include "actuators/WaterPump.h"
#include "storage/LittleFSStorage.h"
#include "communication/WateringSystemWebServer.h"
#include "hardware/RS485Config.h" // Hardware configuration for RS485

// Pin definitions based on hardware.md specification with TXS0108E level shifter
#define PIN_I2C_SDA           21
#define PIN_I2C_SCL           22
#define PIN_RS485_TX          16  // ESP32 TX -> TXS0108E A2 -> B2 -> Click pin13 (DI)
#define PIN_RS485_RX          17  // ESP32 RX <- TXS0108E A1 <- B1 <- Click pin14 (RO)
#define PIN_RS485_DE          25  // Direction control via TXS0108E A3
#define PIN_MAIN_PUMP_CONTROL 26  // Main Water Pump MOSFET Gate (unchanged)
#define PIN_RESERVOIR_PUMP_CONTROL 27  // Reservoir Filling Pump MOSFET Gate (unchanged)
#define PIN_RESERVOIR_LOW_LEVEL   32  // Sensor for low water level in reservoir (unchanged)
#define PIN_RESERVOIR_HIGH_LEVEL  33  // Sensor for high water level in reservoir (unchanged)
#define PIN_STATUS_LED        2       
#define PIN_BUTTON_MANUAL     5       
#define PIN_BUTTON_CONFIG     18

// Other constants
#define SOIL_SENSOR_MODBUS_ADDR 0x01
#define BME280_I2C_ADDR       0x77
#define WIFI_TIMEOUT          60000  // 60 seconds timeout for WiFi connection
#define NTP_SERVER            "0.se.pool.ntp.org"
#define STATUS_CHECK_INTERVAL 5000   // 5 seconds between status checks/display
#define WEB_SERVER_PORT       80
#define CONFIG_FILE_PATH      "/wifi_config.json"
#define AP_SSID               "WateringSystem-Setup"
#define AP_PASSWORD           "watering123"
#define DEFAULT_SSID          "CONFIGURE_ME"

// Global component instances
BME280Sensor envSensor(BME280_I2C_ADDR, "BME280");
HardwareSerial rs485Serial(2);  // Using UART2 for RS485
SP3485ModbusClient modbusClient(&rs485Serial, PIN_RS485_DE); // Using TXS0108E level shifter - hardware managed
ModbusSoilSensor soilSensor(&modbusClient, SOIL_SENSOR_MODBUS_ADDR, "SoilSensor");
WaterPump plantPump(PIN_MAIN_PUMP_CONTROL, "PlantPump");         // Renamed for clarity
WaterPump reservoirPump(PIN_RESERVOIR_PUMP_CONTROL, "ReservoirPump"); // Added new pump for filling reservoir
LittleFSStorage dataStorage;
WateringController controller(&envSensor, &soilSensor, &plantPump, &dataStorage);
WateringSystemWebServer webServer(&controller, &envSensor, &soilSensor, &plantPump, &dataStorage, WEB_SERVER_PORT, &reservoirPump);

// System state
unsigned long lastStatusUpdate = 0;
unsigned long lastButtonCheck = 0;
bool manualButtonPressed = false;
bool configButtonPressed = false;
bool systemReady = false;
bool apMode = false;

// Reservoir system state
bool reservoirPumpEnabled = false;   // Is reservoir pump feature enabled
bool reservoirAutoLevelControl = false; // Is automatic level control enabled
bool reservoirLowLevel = false;      // Is water level low in reservoir
bool reservoirHighLevel = false;     // Is water level high in reservoir
bool reservoirPumpRunning = false;   // Is reservoir pump currently running
unsigned long reservoirPumpStartTime = 0; // When the reservoir pump started
#define RESERVOIR_PUMP_MAX_RUNTIME 300000 // Maximum run time for reservoir pump (5 minutes)

// Restart state (moved to global scope to fix the build error)
bool restartScheduled = false;
unsigned long restartTime = 0;

// WiFi configuration
struct WiFiConfig {
    String ssid;
    String password;
};

WiFiConfig wifiConfig;

// WiFi monitoring and stability variables
unsigned long lastWiFiCheck = 0;
unsigned long lastWiFiReconnect = 0;
unsigned long lastWiFiDiagnostic = 0;
int wifiReconnectAttempts = 0;
int wifiDisconnectCount = 0;
bool wifiStable = false;
const int WIFI_CHECK_INTERVAL = 5000;        // Check WiFi every 5 seconds
const int WIFI_RECONNECT_INTERVAL = 10000;   // Wait 10 seconds between reconnect attempts
const int WIFI_DIAGNOSTIC_INTERVAL = 10000;  // Print diagnostics every 10 seconds (TESTING: was 30000)
const int MAX_RECONNECT_ATTEMPTS = 5;        // Max attempts before longer delay

// Watchdog variables
unsigned long lastLoopTime = 0;
unsigned long loopWatchdogTimeout = 30000;  // 30 seconds watchdog
bool watchdogEnabled = true;

// Forward declarations
void monitorWiFiConnection();
void checkWatchdog();
void feedWatchdog();
bool saveWiFiConfig(const String& ssid, const String& password);
void checkEmergencyWiFiReset();
void handleSerialCommands();

// Forward declarations for essential functions
void handleSerialCommands();
void printWiFiDiagnostics();
void printSystemInfo();
void printWiFiDiagnostics() {
    if (millis() - lastWiFiDiagnostic < WIFI_DIAGNOSTIC_INTERVAL) {
        return;
    }
    lastWiFiDiagnostic = millis();
    
    Serial.println("=== WiFi Diagnostics ===");
    Serial.printf("DEBUG: WiFi diagnostics triggered at %lu ms\n", millis());
    Serial.printf("Status: %s (%d)\n", 
        WiFi.status() == WL_CONNECTED ? "Connected" : "Disconnected", 
        WiFi.status());
        
    if (WiFi.status() == WL_CONNECTED) {
        Serial.printf("SSID: %s\n", WiFi.SSID().c_str());
        Serial.printf("IP: %s\n", WiFi.localIP().toString().c_str());
        Serial.printf("Gateway: %s\n", WiFi.gatewayIP().toString().c_str());
        Serial.printf("Subnet: %s\n", WiFi.subnetMask().toString().c_str());
        Serial.printf("RSSI: %d dBm\n", WiFi.RSSI());
        Serial.printf("Channel: %d\n", WiFi.channel());
        Serial.printf("MAC: %s\n", WiFi.macAddress().c_str());
        
        // Signal quality assessment
        int rssi = WiFi.RSSI();
        String quality;
        if (rssi > -50) quality = "Excellent";
        else if (rssi > -60) quality = "Good";
        else if (rssi > -70) quality = "Fair";
        else if (rssi > -80) quality = "Poor";
        else quality = "Very Poor";
        
        Serial.printf("Signal Quality: %s\n", quality.c_str());
        Serial.printf("Uptime: %lu ms\n", millis());
        
        // Connection stability stats
        Serial.printf("Disconnects: %d\n", wifiDisconnectCount);
        Serial.printf("Reconnect attempts: %d\n", wifiReconnectAttempts);
        Serial.printf("Stable: %s\n", wifiStable ? "Yes" : "No");    }
    Serial.println("========================");
    Serial.printf("DEBUG: WiFi diagnostics completed at %lu ms\n", millis());
}

/**
 * @brief Enhanced WiFi connection with better error handling
 */
bool connectToWiFiEnhanced() {
    if (wifiConfig.ssid.isEmpty()) {
        Serial.println("No WiFi configuration available");
        return false;
    }
    
    Serial.printf("Connecting to WiFi network: %s\n", wifiConfig.ssid.c_str());
    
    // Configure WiFi for better stability
    WiFi.mode(WIFI_STA);
    WiFi.setAutoReconnect(false);  // Handle reconnection manually
    WiFi.setSleep(false);          // Disable WiFi sleep mode
    
    // Disconnect first to ensure clean state
    WiFi.disconnect(true);
    delay(100);
    
    // Begin connection
    WiFi.begin(wifiConfig.ssid.c_str(), wifiConfig.password.c_str());
    
    // Wait for connection with timeout
    unsigned long startAttemptTime = millis();
    while (WiFi.status() != WL_CONNECTED && 
           millis() - startAttemptTime < WIFI_TIMEOUT) {
        Serial.print(".");
        digitalWrite(PIN_STATUS_LED, !digitalRead(PIN_STATUS_LED));  // Toggle LED
        delay(500);
    }
    
    if (WiFi.status() != WL_CONNECTED) {
        Serial.println("\nFailed to connect to WiFi");
        wifiReconnectAttempts++;
        return false;
    }
    
    Serial.println("\nWiFi connected successfully");
    Serial.printf("IP address: %s\n", WiFi.localIP().toString().c_str());
    Serial.printf("Signal strength: %d dBm\n", WiFi.RSSI());
    
    wifiReconnectAttempts = 0;  // Reset counter on successful connection
    wifiStable = true;
    apMode = false;
    
    return true;
}

/**
 * @brief Initialize system hardware
 */
void initHardware() {
  // Initialize serial port for debugging
  Serial.begin(115200);
  Serial.println("\n\nWateringSystem v2.3 - Hardware-Managed Power");
  Serial.println("Architecture: LDO-powered domains with TXS0108E level shifting");
  
  // Initialize status LED
  pinMode(PIN_STATUS_LED, OUTPUT);
  digitalWrite(PIN_STATUS_LED, HIGH);  // Turn on while initializing
  
  // Initialize buttons with pull-ups
  pinMode(PIN_BUTTON_MANUAL, INPUT_PULLUP);
  pinMode(PIN_BUTTON_CONFIG, INPUT_PULLUP);
  
  // Initialize reservoir level sensors with pull-ups
  pinMode(PIN_RESERVOIR_LOW_LEVEL, INPUT_PULLUP);
  pinMode(PIN_RESERVOIR_HIGH_LEVEL, INPUT_PULLUP);
    // Initialize I2C for BME280 (ESP32 domain)
  Wire.begin(PIN_I2C_SDA, PIN_I2C_SCL);
  Serial.println("I2C initialized for BME280");
    // Initialize RS485 UART with TXS0108E level shifter
  rs485Serial.begin(9600, SERIAL_8N1, PIN_RS485_RX, PIN_RS485_TX);
  Serial.println("RS485 UART initialized (TXS0108E level shifter - OE tied to VCC)");
  
  // Hardware stabilization delay (much shorter with TXS0108E)
  delay(100);
  
  Serial.println("Hardware initialization completed with TXS0108E level shifting");
}

/**
 * @brief Load WiFi configuration from file
 * @return true if valid configuration loaded, false otherwise
 */
bool loadWiFiConfig() {
  if (!LittleFS.exists(CONFIG_FILE_PATH)) {
    Serial.println("No WiFi configuration file found");
    // Create default configuration file
    saveWiFiConfig(DEFAULT_SSID, "");
    return false;
  }
  
  File configFile = LittleFS.open(CONFIG_FILE_PATH, "r");
  if (!configFile) {
    Serial.println("Failed to open WiFi configuration file");
    return false;
  }
  
  StaticJsonDocument<256> doc;
  DeserializationError error = deserializeJson(doc, configFile);
  configFile.close();
  
  if (error) {
    Serial.printf("Failed to parse WiFi configuration file: %s\n", error.c_str());
    return false;
  }
  
  wifiConfig.ssid = doc["ssid"].as<String>();
  wifiConfig.password = doc["password"].as<String>();
  
  Serial.printf("Loaded WiFi configuration - SSID: %s\n", wifiConfig.ssid.c_str());
  
  // Check if this is the default configuration
  if (wifiConfig.ssid == DEFAULT_SSID) {
    Serial.println("Default WiFi configuration detected - AP mode required");
    return false;
  }
  
  return true;
}

/**
 * @brief Save WiFi configuration to file
 * @param ssid WiFi network name
 * @param password WiFi password
 * @return true if saved successfully, false otherwise
 */
bool saveWiFiConfig(const String &ssid, const String &password) {
  StaticJsonDocument<256> doc;
  
  doc["ssid"] = ssid;
  doc["password"] = password;
  
  File configFile = LittleFS.open(CONFIG_FILE_PATH, "w");
  if (!configFile) {
    Serial.println("Failed to open WiFi configuration file for writing");
    return false;
  }
  
  if (serializeJson(doc, configFile) == 0) {
    Serial.println("Failed to write WiFi configuration file");
    configFile.close();
    return false;
  }
  
  configFile.close();
  Serial.println("WiFi configuration saved successfully");
  
  // Update current configuration
  wifiConfig.ssid = ssid;
  wifiConfig.password = password;
  
  // Schedule a restart after a short delay
  // This allows the response to be sent back to the client
  Serial.println("Scheduling restart in 3 seconds...");
  delay(100);  // Short delay to ensure serial output is sent
  
  // Set global restart variables
  restartScheduled = true;
  restartTime = millis() + 3000;  // 3 second delay
  
  return true;
}

/**
 * @brief Start ESP32 in Access Point mode for configuration
 */
void startAccessPointMode() {
  Serial.println("Starting Access Point mode for configuration");
  
  WiFi.mode(WIFI_AP);
  WiFi.softAP(AP_SSID, AP_PASSWORD);
  
  Serial.printf("Access Point started - SSID: %s, IP: %s\n", 
                AP_SSID, WiFi.softAPIP().toString().c_str());
  
  apMode = true;
}

/**
 * @brief Connect to WiFi network using saved configuration (legacy wrapper)
 * @return true if connected successfully, false otherwise
 */
bool connectToWiFi() {
  return connectToWiFiEnhanced();
}
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
void loop() {
  // Check if restart has been scheduled
  if (restartScheduled && millis() > restartTime) {
    Serial.println("Restarting system now...");
    delay(500);  // Allow cleanup to complete
    ESP.restart();
  }
    // Handle Serial commands for debugging
  handleSerialCommands();
  
  // Update the controller
  controller.update();
  
  // Handle user input (buttons)
  handleButtons();
  
  // Update status display periodically
  updateStatus();
  
  // Handle reservoir pump control
  handleReservoirPump();
  
  // LED status indication
  if (apMode) {
    // Fast blinking in AP mode
    digitalWrite(PIN_STATUS_LED, ((millis() / 200) % 2) ? HIGH : LOW);
  } else if (plantPump.isRunning()) {
    // Medium blinking when pump is running
    digitalWrite(PIN_STATUS_LED, ((millis() / 500) % 2) ? HIGH : LOW);
  } else {
    // Just a short blink every 3 seconds to show system is running
    digitalWrite(PIN_STATUS_LED, ((millis() % 3000) < 100) ? HIGH : LOW);  }
    // Monitor and maintain WiFi connection
  monitorWiFiConnection();
  
  // Feed watchdog to prevent system restart
  feedWatchdog();
  
  // Check watchdog
  checkWatchdog();
  
  // Allow other tasks to run
  yield();
}

/**
 * @brief Reset WiFi settings and restart in AP mode
 */
void resetWiFiSettings() {
    Serial.println("Resetting WiFi settings and restarting in AP mode...");
    
    // Stop current connections
    WiFi.disconnect(true);
    WiFi.mode(WIFI_OFF);
    
    // Remove WiFi config file
    if (LittleFS.exists(CONFIG_FILE_PATH)) {
        LittleFS.remove(CONFIG_FILE_PATH);
        Serial.println("WiFi configuration file removed");
    }
    
    // Create default configuration
    saveWiFiConfig(DEFAULT_SSID, "");
    
    Serial.println("System will restart in AP mode for reconfiguration");
    delay(2000);
    ESP.restart();
}

/**
 * @brief Emergency WiFi recovery - force AP mode if button held during startup
 */
void checkEmergencyWiFiReset() {
    // Check if config button is held down during startup
    int configButtonHoldTime = 0;
    while (digitalRead(PIN_BUTTON_CONFIG) == LOW && configButtonHoldTime < 50) {
        delay(100);
        configButtonHoldTime++;
        digitalWrite(PIN_STATUS_LED, configButtonHoldTime % 2);  // Blink LED
    }
    
    if (configButtonHoldTime >= 50) {  // Button held for 5+ seconds
        Serial.println("Emergency WiFi reset triggered!");
        resetWiFiSettings();
    }
}

/**
 * @brief Simple software watchdog to prevent system hangs
 */
void feedWatchdog() {
    lastLoopTime = millis();
}

/**
 * @brief Check if system is hanging and restart if needed
 */
void checkWatchdog() {
    if (!watchdogEnabled) return;
    
    if (millis() - lastLoopTime > loopWatchdogTimeout) {
        Serial.println("WATCHDOG: System appears to be hanging - restarting...");
        delay(1000);
        ESP.restart();
    }
}

/**
 * @brief Monitor and maintain WiFi connection
 */
void monitorWiFiConnection() {
    if (apMode) return;  // Skip monitoring in AP mode
    
    if (millis() - lastWiFiCheck < WIFI_CHECK_INTERVAL) {
        return;
    }
    lastWiFiCheck = millis();
    
    // Print diagnostics periodically
    printWiFiDiagnostics();
    
    // Check connection status
    if (WiFi.status() != WL_CONNECTED) {
        if (wifiStable) {
            Serial.println("WiFi connection lost!");
            wifiDisconnectCount++;
            wifiStable = false;
        }
        
        // Attempt reconnection with exponential backoff
        if (millis() - lastWiFiReconnect > WIFI_RECONNECT_INTERVAL) {
            lastWiFiReconnect = millis();
            
            Serial.printf("Attempting WiFi reconnection (%d/%d)...\n", 
                         wifiReconnectAttempts + 1, MAX_RECONNECT_ATTEMPTS);
            
            if (connectToWiFiEnhanced()) {
                Serial.println("WiFi reconnected successfully");
            } else if (wifiReconnectAttempts >= MAX_RECONNECT_ATTEMPTS) {
                Serial.println("Max reconnect attempts reached, waiting longer...");
                lastWiFiReconnect = millis() + 60000;  // Wait 1 minute before trying again
                wifiReconnectAttempts = 0;  // Reset counter
            }
        }
    } else {
        // Connection is good, check signal quality
        int rssi = WiFi.RSSI();
        if (rssi < -80 && wifiStable) {
            Serial.printf("WARNING: Weak WiFi signal (%d dBm)\n", rssi);
        }
        
        if (!wifiStable) {
            Serial.println("WiFi connection restored and stable");
            wifiStable = true;
        }
    }
}

/**
 * @brief Handle Serial commands for testing and debugging
 */
void handleSerialCommands() {
  if (Serial.available()) {
    String command = Serial.readStringUntil('\n');
    command.trim();
    command.toLowerCase();
      Serial.printf("Received command: '%s'\n", command.c_str());
      if (command == "soil" || command == "sensor") {
      Serial.println("Testing soil sensor...");
      if (soilSensor.read()) {
        Serial.printf("Moisture: %.1f%%, Temperature: %.1f°C, pH: %.1f\n", 
                      soilSensor.getMoisture(), soilSensor.getTemperature(), soilSensor.getPH());
        Serial.printf("EC: %.0f µS/cm, NPK(N/P/K): %.0f/%.0f/%.0f mg/kg\n", 
                      soilSensor.getEC(), soilSensor.getNitrogen(), 
                      soilSensor.getPhosphorus(), soilSensor.getPotassium());
      } else {
        Serial.printf("Sensor read failed (Error: %d)\n", soilSensor.getLastError());
      }
    }
    else if (command == "rs485test" || command == "test") {
      Serial.println("\n=== RS485 Diagnostic Test ===");

      // Step 1: Verify DE pin control
      Serial.printf("DE pin (GPIO%d) test:\n", PIN_RS485_DE);
      digitalWrite(PIN_RS485_DE, HIGH);
      Serial.printf("  DE set HIGH (TX mode) - measure 3.3V on GPIO%d, 5V on TXS0108E B3\n", PIN_RS485_DE);
      delay(100);
      digitalWrite(PIN_RS485_DE, LOW);
      Serial.printf("  DE set LOW  (RX mode)\n");
      delay(100);

      // Step 2: Build and show the raw Modbus request
      uint8_t request[8];
      request[0] = SOIL_SENSOR_MODBUS_ADDR;
      request[1] = 0x03;
      request[2] = 0x00; request[3] = 0x00;  // Start register 0x0000
      request[4] = 0x00; request[5] = 0x09;  // 9 registers
      // CRC16-MODBUS calculation
      uint16_t crc = 0xFFFF;
      for (int pos = 0; pos < 6; pos++) {
        crc ^= (uint16_t)request[pos];
        for (int i = 0; i < 8; i++) {
          if (crc & 0x0001) { crc >>= 1; crc ^= 0xA001; }
          else { crc >>= 1; }
        }
      }
      request[6] = crc & 0xFF;
      request[7] = crc >> 8;

      Serial.printf("TX frame: ");
      for (int i = 0; i < 8; i++) Serial.printf("%02X ", request[i]);
      Serial.println();

      // Step 3: Send manually and capture raw response
      // Clear RX buffer
      while (rs485Serial.available()) rs485Serial.read();

      // Transmit
      digitalWrite(PIN_RS485_DE, HIGH);
      delayMicroseconds(100);
      rs485Serial.write(request, 8);
      rs485Serial.flush();
      delayMicroseconds(100);
      digitalWrite(PIN_RS485_DE, LOW);

      // Wait and capture everything
      Serial.printf("Waiting for response (3s timeout)...\n");
      unsigned long startTime = millis();
      uint8_t rxBuf[64];
      int rxCount = 0;

      while ((millis() - startTime) < 3000 && rxCount < 64) {
        if (rs485Serial.available()) {
          rxBuf[rxCount++] = rs485Serial.read();
        }
        yield();
      }

      Serial.printf("RX bytes received: %d\n", rxCount);
      if (rxCount > 0) {
        Serial.printf("RX data: ");
        for (int i = 0; i < rxCount; i++) Serial.printf("%02X ", rxBuf[i]);
        Serial.println();
      } else {
        Serial.println("No response - possible causes:");
        Serial.println("  1. TX signal not reaching sensor (check TXS0108E A1->B1)");
        Serial.println("  2. RX signal not returning (check TXS0108E B2->A2)");
        Serial.println("  3. RS485 A/B lines swapped");
        Serial.println("  4. Sensor address mismatch (expecting 0x01)");
        Serial.println("  5. DE/RE not switching (check TXS0108E A3->B3)");
      }

      // Step 4: Also try via the normal modbusClient
      Serial.println("\nRetrying via modbusClient...");
      uint16_t testData[9];
      bool success = modbusClient.readHoldingRegisters(SOIL_SENSOR_MODBUS_ADDR, 0x0000, 9, testData);

      if (success) {
        Serial.println("OK! Communication successful!");
        for (int i = 0; i < 9; i++) {
          Serial.printf("  Reg[0x%04X]: %d (0x%04X)\n", i, testData[i], testData[i]);
        }
      } else {
        Serial.printf("Failed (Error: %d)\n", modbusClient.getLastError());
      }
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

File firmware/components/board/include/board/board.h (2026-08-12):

/**
 * @file board.h
 * @brief Board abstraction: pin mapping and feature flags per board revision.
 *
 * The board revision is selected at configure time via Kconfig
 * (menu "WateringSystem" -> "Board revision"), typically through the
 * sdkconfig.board.* overlay files:
 *
 *   idf.py -DSDKCONFIG_DEFAULTS="sdkconfig.defaults;sdkconfig.board.rev2" build
 *
 * All application and driver code must take pin numbers and polarity from
 * this header — never hard-code GPIO numbers elsewhere.
 */

#ifndef WATERINGSYSTEM_BOARD_BOARD_H
#define WATERINGSYSTEM_BOARD_BOARD_H

#include "sdkconfig.h"

#if CONFIG_BOARD_REV1_DEVKIT

/* ------------------------------------------------------------------------
 * Rev 1 — ESP32 devkit + breakout board (TXS0108E level shifter + SP3485)
 * Pins follow the running Arduino firmware (src/main.cpp), the
 * field-verified source of truth. Note: docs/hardware.md lists RS485
 * TX/RX swapped — see docs/parity-checklist.md QUIRK 6.
 * ------------------------------------------------------------------------ */

#define BOARD_NAME                      "rev1_devkit"

/* I2C bus (BME280) */
#define BOARD_PIN_I2C_SDA               21
#define BOARD_PIN_I2C_SCL               22

/* RS485 (SP3485 via TXS0108E, manual direction control).
 * TX=16/RX=17 per src/main.cpp PIN_RS485_TX/PIN_RS485_RX (source of truth;
 * docs/hardware.md has them swapped — docs/parity-checklist.md QUIRK 6). */
#define BOARD_PIN_RS485_TX              16
#define BOARD_PIN_RS485_RX              17
#define BOARD_HAS_RS485_DE              1
#define BOARD_PIN_RS485_DE              25
/* Modbus RTU runs on UART2 at 9600 baud 8N1 (parity: legacy Serial2,
 * docs/parity-checklist.md §5). */
#define BOARD_RS485_UART_PORT           2

/* Pumps (MOSFET gates, active high).
 * Rev 1 has both pumps (plant + reservoir fill) — two-pump topology. */
#define BOARD_PIN_MAIN_PUMP             26
#define BOARD_HAS_RESERVOIR_PUMP        1
#define BOARD_PIN_RESERVOIR_PUMP        27

/* Reservoir level sensors (XKC-Y26), low/high mark on 32/33 with internal
 * pull-ups (parity: src/main.cpp:37-38, 231-233; docs/parity-checklist.md
 * line 95).
 * Rev 1: sensor OUT routed non-inverting through TXS0108E. XKC-Y26 OUT is
 * active HIGH (water present = HIGH), so the GPIO is active HIGH (FW-5).
 * Debounce: stability window before a reported state change (deliberate
 * divergence from legacy's bare reads — docs/parity-checklist.md §6); a
 * hardware property of the sensor class, hence a board macro, not Kconfig.
 * Settle: 0 ms — the rev1 sensor rail is permanently on (FW-3 applies to
 * rev2's switched rail only); debounce warm-up subsumes settle here. */
#define BOARD_PIN_LEVEL_LOW             32
#define BOARD_PIN_LEVEL_HIGH            33
#define BOARD_LEVEL_ACTIVE_LOW          0
#define BOARD_LEVEL_DEBOUNCE_MS         300
#define BOARD_LEVEL_SETTLE_MS           0

/* Pump current monitoring: none on rev1 (BOARD_INA226_ADDR is deliberately
 * NOT defined — unguarded references fail the build, RS485-DE pattern). */
#define BOARD_HAS_INA226                0

/* Status LED */
#define BOARD_PIN_STATUS_LED            2

/* Buttons (manual watering trigger, WiFi config/AP mode).
 * Rev 1 has both physical buttons; the config button drives the boot
 * provisioning-force path (feature 007, docs/parity-checklist.md §7). */
#define BOARD_HAS_BTN_MANUAL            1
#define BOARD_PIN_BTN_MANUAL            5
#define BOARD_HAS_BTN_CONFIG            1
#define BOARD_PIN_BTN_CONFIG            18

/* Power/rail monitoring: none on rev1. The devkit rig runs off USB with a
 * permanently powered sensor rail, so battery sense, buck power-good and
 * sensor-rail enable do not exist here. The pin macros are deliberately NOT
 * defined (RS485-DE pattern): unguarded references fail the build. */
#define BOARD_HAS_VBAT_SENSE            0
#define BOARD_HAS_PWR_PG                0
#define BOARD_HAS_SENS_PWR_EN           0

#elif CONFIG_BOARD_REV2
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

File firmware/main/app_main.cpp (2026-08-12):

/**
 * @file app_main.cpp
 * @brief WateringSystem firmware entry point.
 *
 * The very first action at boot is to force every pump output that exists
 * on this board to a safe OFF state. This fail-safe MUST stay first in
 * app_main in all future phases: pumps are always off after power-on,
 * watchdog reset and OTA restart, before any other initialization runs.
 * The pump set is capability-aware (feature 006): rev1 has two pumps,
 * rev2 is a single-pump node (BOARD_HAS_RESERVOIR_PUMP = 0) — the
 * invariant "every pump that exists is OFF first" is unchanged.
 *
 * Corollary: no translation unit in this firmware may contain non-trivial
 * static/global constructors — they run before app_main and would execute
 * ahead of (and thus bypass) this fail-safe. Keep all initialization
 * explicit, inside or after pumps_force_off().
 *
 * Hardware dependency: the pump MOSFET gate pull-down resistors must hold
 * both pumps off while the GPIOs are hi-Z, i.e. during boot ROM /
 * bootloader execution and after an abort() below. The software fail-safe
 * narrows the hi-Z window; the pull-downs cover it.
 */

#include "board/board.h"
#include "esp_app_desc.h"
#include "esp_event.h"
#include "esp_idf_version.h"
#include "esp_log.h"
#include "esp_netif.h"
#include "esp_system.h"
#include "driver/gpio.h"
#include "freertos/FreeRTOS.h"
#include "freertos/task.h"
#include "nvs_flash.h"

#include "actuators/EspTimeProvider.h"
#include "actuators/GpioWaterPump.h"
#include "actuators/LockedWaterPump.h"
#include "events/EventLogger.h"
#include "sensors/Bme280Sensor.h"
#include "sensors/DebouncedLevelSensor.h"
#include "sensors/EspI2cBus.h"
#include "sensors/EspModbusClient.h"
#include "sensors/GpioLevelSensor.h"
#include "sensors/LockedEnvironmentalSensor.h"
#include "sensors/LockedLevelSensor.h"
#include "sensors/LockedModbusClient.h"
#include "sensors/LockedSoilSensor.h"
#include "sensors/ModbusSoilSensor.h"
#if BOARD_HAS_INA226
// INA226 headers only on equipped boards: Ina226Sensor.cpp is not in the
// rev1 target build at all (sensors/CMakeLists.txt) — FR-011.
#include "sensors/Ina226Sensor.h"
#include "sensors/LockedPowerSensor.h"
#endif
#include "api/ApiServer.h"
#include "control/WateringController.h"
#if BOARD_HAS_RESERVOIR_PUMP
#include "control/ReservoirController.h"
#endif
#include "network/EspWifiDriver.h"
#include "network/ProvisioningPortal.h"
#include "network/WifiBootMode.h"
#include "network/WifiManager.h"
#include "network/WifiState.h"
#include "storage/LittleFsDataStorage.h"
#include "storage/LockedConfigStore.h"
#include "storage/LockedDataStorage.h"
#include "storage/NvsConfigStore.h"
#include "storage/StorageMount.h"
#include "time/SntpClient.h"
#include "time/SystemWallClock.h"

#include "diag_console.h"
#include "sensor_task.h"
#include "watering_task.h"
#include "system_observer.h"
#include "task_watchdog.h"
#include "wifi_task.h"

static const char *TAG = "app_main";

#if BOARD_HAS_BTN_CONFIG
// Config-button emergency-provisioning hold (feature 007, US3). Parity
// (docs/parity-checklist.md §7): the config button held >= 5 s during startup
// forces WiFi provisioning; the status LED blinks every 100 ms while the hold
// is being confirmed so the operator sees the reset registering (§7/§9). This
// 100 ms button-hold blink is distinct from the wifi task's 500 ms
// connect-attempt toggle (that one runs later, from wifi_task.cpp).
static constexpr uint32_t kConfigButtonHoldMs = 5000;   // hold to force prov.
static constexpr uint32_t kConfigButtonBlinkMs = 100;   // LED toggle interval
#endif

/**
 * @brief Drive every pump GPIO that exists on this board to a safe OFF
 * state (output, level 0).
 *
 * Capability-aware (feature 006, FR-007): on two-pump boards (rev1) both
 * the plant and the reservoir pump are forced off; on single-pump boards
 * (BOARD_HAS_RESERVOIR_PUMP == 0, rev2) exactly the plant pump is — the
 * reservoir pin does not exist there and any unguarded reference is a
 * compile error (board.h enforcement pattern).
 *
 * Pumps are switched by N-channel MOSFET gates and are active high,
 * so level 0 means pump off.
 *
 * Error handling is explicit (not ESP_ERROR_CHECK): this safety check must
 * fire regardless of the configured assertion level (ESP_ERROR_CHECK
 * degrades to a no-op when assertions are disabled via NDEBUG).
 */
static void pumps_force_off(void)
{
    uint64_t pump_mask = 1ULL << BOARD_PIN_MAIN_PUMP;
#if BOARD_HAS_RESERVOIR_PUMP
    pump_mask |= 1ULL << BOARD_PIN_RESERVOIR_PUMP;
#endif
    const gpio_config_t pump_cfg = {
        .pin_bit_mask = pump_mask,
        .mode = GPIO_MODE_OUTPUT,
        .pull_up_en = GPIO_PULLUP_DISABLE,
        .pull_down_en = GPIO_PULLDOWN_DISABLE,
        .intr_type = GPIO_INTR_DISABLE,
    };

    // Set output levels to 0 BEFORE switching the pins to output mode, so
    // the pins never glitch high when the output driver is enabled.
    esp_err_t err = gpio_set_level(static_cast<gpio_num_t>(BOARD_PIN_MAIN_PUMP), 0);
    if (err != ESP_OK) {
        ESP_LOGE(TAG, "FATAL: pump fail-safe init failed: %s", esp_err_to_name(err));
        abort();
    }
#if BOARD_HAS_RESERVOIR_PUMP
    err = gpio_set_level(static_cast<gpio_num_t>(BOARD_PIN_RESERVOIR_PUMP), 0);
    if (err != ESP_OK) {
        ESP_LOGE(TAG, "FATAL: pump fail-safe init failed: %s", esp_err_to_name(err));
        abort();
    }
#endif
    err = gpio_config(&pump_cfg);
    if (err != ESP_OK) {
        ESP_LOGE(TAG, "FATAL: pump fail-safe init failed: %s", esp_err_to_name(err));
        abort();
    }
}
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

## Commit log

2025-04-15 Rename WebServer to WateringSystemWebServer to avoid conflicts
    - Renamed class and files to WateringSystemWebServer to avoid name conflicts with ESP32's built-in WebServer
    - Created new header and implementation files with the new name
    - Updated main.cpp to use the new header file
    - Maintained the same functionality without behavioral changes
    - Removed old WebServer files
    [main.cpp]
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2025-04-16 Add reservoir pump functionality with auto-fill feature
    - Add new hardware support for reservoir pump and water level sensors
    - Implement reservoir control logic in main.cpp
    - Update web interface with reservoir management controls
    - Update documentation with reservoir pump specifications
    - Fix getReservoirStatus function to return bool according to callback type
    - Fix method name in ModbusSoilSensor from writeHoldingRegister to writeSingleRegister
    [main.cpp]
2025-05-05 Fix manual watering button functionality and add debug logging
    - Add debug logging to WateringSystemWebServer for troubleshooting API calls
    - Enhance WateringController with additional logging for manual watering
    - Improve WaterPump class with detailed operation logs
    - Update script.js with DOM element verification and direct onclick handler
    - Add cache-busting version parameter to script.js in index.html
    - Fix event handling for manual watering button
    [WaterPump.cpp, WateringController.cpp]
2025-05-05 Fix LittleFS file path handling and config file management
    - Update LittleFSStorage to properly handle file paths with leading slashes
    - Add automatic creation of config.json file when missing
    - Improve error handling and logging for file operations
    - Fix endpoint path handling in WateringSystemWebServer class
    - Update LittleFSStorage constructor to handle String objects correctly
    - Add detailed logging for debugging file path issues
    [main.cpp]
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2025-05-05 add: include favicon and update header files
    - Add favicon.ico for web interface
    - Update WateringSystemWebServer.h with proper function declarations
    - Improve debug logging in WaterPump.cpp for better troubleshooting
    - Complete the fix for the JSON handling issue
    [WaterPump.cpp]
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2025-06-09 Remove auto-generated documentation files and enhance WiFi stability
    - Remove outdated documentation files that were auto-restored by VS Code
    - Keep only essential docs: requirements.md, architecture.md, hardware.md
    - Enhanced WiFi stability with monitoring, diagnostics, and auto-reconnection
    - Added software watchdog and emergency WiFi reset functionality
    - Improved web interface connection status handling
    [main.cpp]
2025-06-09 Implement dual-level reservoir pump control system
    - Add master reservoir feature toggle for complete system enable/disable
    - Implement automatic level control toggle as secondary control layer
    - Replace simple automatic logic with sophisticated sensor-based control
    - New sensor logic: LOW+HIGH=stop (full), LOW+!HIGH=stop (sufficient), !LOW+!HIGH=start (empty)
    - Add new API endpoints: enable-auto-level, disable-auto-level
    - Extend web UI with hierarchical toggle switches
    - Maintain all existing safety features (timeout, high-level stop)
    - Preserve manual control functionality alongside automatic control
    - Update status reporting to include automatic level control state
    - Add proper state man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
    [WateringController.cpp, main.cpp]
2025-06-10 Fix critical sensor failure and implement emergency safety measures
    - Add brownout detector disable to prevent WiFi-related resets
    - Implement comprehensive fail-safe mechanisms for sensor timeouts
    - Add timestamp-based sensor validation with 30-second timeout
    - Emergency pump stop when sensor data unavailable
    - Enhanced debug infrastructure for sensor initialization
    - Improve RS485 communication timing and error handling
    - Optimize web interface refresh rates and performance
    - Add serial command interface for testing and diagnostics
    - Correct NPK sensor register mappings per documentation
    - Remove excessive debug logging for better performance
    [WaterPump.cpp, WateringController.cpp, main.cpp]
2025-06-11 Upgrade from FOD817 optocouplers to TXS0108E level shifter
    - Replace FOD817BSD optical isolation with TXS0108E bidirectional level shifter
    - Achieve 1800x faster signal propagation (10ns vs 18µs)
    - Support up to 110 Mbps data rate vs ~1 Mbps limitation
    - Reduce component count from 3 optocouplers to 1 level shifter IC
    - Update timing constants for faster DE/RE switching (10µs vs 200µs)
    - Modify GPIO pin assignments for TXS0108E Output Enable (GPIO 26)
    - Update hardware documentation and specifications
    - Reduce power consumption (2mA vs 30mA for optocouplers)
    - Maintain cost-effectiveness while improving performance
    - Update all comments and documentation references
    [RS485Config.h, main.cpp]
2025-06-11 Correct FOD817 to TXS0108E component replacement - GPIO unchanged
    - Replace FOD817BSD optocouplers with TXS0108E level shifter (component only)
    - TXS0108E OE pin connected to VCC (always enabled, no GPIO control needed)
    - Maintain all original GPIO pin assignments (26, 27, 32, 33 unchanged)
    - Keep faster timing improvements for TXS0108E (10µs vs 200µs switching)
    - Update hardware documentation with correct TXS0108E specifications
    - Remove unnecessary GPIO initialization in SP3485ModbusClient
    - Achieve 1800x faster propagation (10ns vs 18µs) with same pinout
    - Reduce power consumption (2mA vs 30mA) and cost (78% reduction)
    - Maintain full backward compatibility with existing GPIO assignmen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
    [RS485Config.h, main.cpp]
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2025-07-05 Fix manual watering mode and remove soil sensor debug logging
    - Add manual mode support to WaterPump with isManualMode() and setManualMode()
    - Modify safety functions to only apply to automatic watering mode
    - Manual watering now bypasses sensor-based safety checks
    - Remove excessive DEBUG-INIT logging from soil sensor initialization
    - Fix timing display bug in pump debug messages
    - Add comprehensive debug logging for pump operations with mode tracking
    - Manual watering will now run full duration even with non-functional soil sensor
    This allows manual watering to work independently of soil sensor status while maintaining safety for automatic watering operations.
    [WaterPump.cpp, WateringController.cpp]
2025-07-24 Fix RS485 communication and update documentation
    Major improvements to RS485 Modbus soil sensor communication:
    Hardware fixes:
    - Fix GPIO pin configuration: TX=GPIO17, RX=GPIO16 (was swapped)
    - Optimize TXS0108E timing delays from 10µs to 50µs for reliable switching
    - Update RS485Config.h with verified timing constants
    Software improvements:
    - Remove debug logging from SP3485ModbusClient for production use
    - Implement robust Modbus RTU protocol with error handling
    - Add smart parsing for timing offset corrections
    - Replace hardcoded delays with configuration constants
    Documentation updates:
    - Update hardware.md with corrected pin assignments and verified timings
    - Add implementation not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
    [RS485Config.h, main.cpp]
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2025-07-29 Add rs485test diagnostic command and fix soil sensor communication
    - Implement rs485test/test commands in handleSerialCommands()
    - Add isolated RS485 client testing functionality
    - Parse and display raw register values with detailed output
    - Enable runtime diagnostics for soil sensor troubleshooting
    - Successfully resolved Error 3 communication issues
    - Production system now fully functional with soil sensor readings
    [main.cpp]
2025-08-22 Change license from MIT to AGPL-3.0-or-later
    - Replace LICENSE with full AGPL-3.0-or-later text
    - Add SPDX headers to all source files (.cpp, .h)
    - Update CONTRIBUTING.md with DCO and copyleft requirements
    - Preserve attribution and require source sharing for modifications
    - Ensure commercial use allowed but changes must be returned
    [RS485Config.h, WaterPump.cpp]
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2026-04-12 Fixa RS485 TX/RX pin-korsning och förbättra diagnostik
    Rotorsak: KiCad-schemats nätnamn (RS485_TX_5V/RS485_RX_5V) var
    namngivna ur ESP32-perspektiv men Click-kortets TX/RX-labels är
    ur MAX485-perspektiv. Resulterade i att ESP32 TX kopplades till
    MAX485 RO (output) och ESP32 RX till MAX485 DI (input).
    Ändringar:
    - Byt RS485 TX pin till GPIO16 och RX pin till GPIO17 (main.cpp + RS485Config.h)
    - Ersätt rs485test-kommandot: använder befintlig rs485Serial istället för
    att skapa en ny HardwareSerial(2) som kraschade UART-drivrutinen
    - rs485test visar nu rå TX/RX-bytes för felsökning
    - Uppdatera platformio.ini från WSL-sökvägar till Windows COM-port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
    [RS485Config.h, main.cpp]
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2026-04-12 Fixa inverterad avläsning av XKC-Y26 reservoarsensorer
    XKC-Y26 vattensensorer ger HIGH vid vatten (active HIGH), men koden
    läste dem som active LOW. Verifierat mot KiCad-schema: sensorerna går
    via TXS0108E (icke-inverterande) till ESP32 GPIO32/33.
    [main.cpp]
2026-06-09 hardware: commit April design work — schematic pin fixes, PCB layout session, rev2 BOM (THVD1426), JLCPCB production files
    [WateringSystem-rev2-BOM-LCSC.csv, WateringSystem-rev2-BOM.csv, WateringSystem.kicad_pcb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]
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2026-06-10 feat(firmware): add ESP-IDF skeleton with board abstraction and A/B partition layout
    - ESP-IDF v6.0.1 project (C++), pinned via Dockerfile (espressif/idf:v6.0.1)
    - Kconfig board choice BOARD_REV1_DEVKIT / BOARD_REV2 with board component
    (pin maps, RS485 DE-less rev2, level-sensor polarity per board)
    - 4MB partition table: 2x 1.5MB OTA app slots + NVS + littlefs
    - Fail-safe app_main: pumps forced off before any other init, explicit
    error handling independent of assertion level
    - Pinned managed components: esp-modbus 2.1.2, littlefs 1.22.1
    (dependencies.lock tracked)
    - Both board variants build green in the pinned container
    [partitions.csv]
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2026-06-10 feat(firmware): port pump actuator layer with serialized access and console diagnostics
    - interfaces component (header-only, zero IDF deps): IActuator, IWaterPump
    (runFor/stop/update contract with StopReason), ITimeProvider
    - actuators component: WaterPump base holds ALL timing/safety logic (timed
    runs only, hard 300 s max-runtime enforced in update(), paired output
    transitions, runtime statistics) behind a single virtual applyOutput;
    GpioWaterPump (active-HIGH MOSFET, glitch-free off-first init, explicit
    error handling); EspTimeProvider; header-only test doubles
    - LockedWaterPump decorator serializes pump access between the console REPL
    task and the main update loop (review find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
    [GpioWaterPump.cpp, WaterPump.cpp, app_main.cpp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]
2026-06-10 feat(board): complete pin tables with LED/buttons and compile-time sanity checks
    - status LED 2, manual button 5, config button 18 on both boards (rev2
    provisional, TODO(SYNC1))
    - preprocessor sanity block: pin distinctness and RS485 DE flag/macro
    iff-consistency fail the build instead of producing a wrong binary
    - firmware docs: pump layer, concurrency rule (LockedWaterPump), console
    diagnostics, host-test commands
    [board.h]
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2026-06-12 feat(storage): IConfigStore contract and NvsConfigStore with host tests
    User story 1 (P1 MVP) of the storage feature: typed, validated
    configuration in NVS with compiled-in factory defaults.
    - IConfigStore interface header (host-includable, no IDF includes) with
    the defaults/ranges from data-model.md as the single source of truth
    - NvsConfigStore: namespace wscfg, one NVS entry per item, floats as u32
    bit patterns, per-operation RAII handles (factoryReset erases the
    partition, so no handle is ever held), getters shadow missing or
    out-of-range stored values with defaults, setters reject out-of-range
    input, factory reset via nvs_flash_erase_partition + nvs_flash_init,
    credential v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
    [IConfigStore.h]
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2026-06-12 feat(firmware): storage boot wiring in app_main
    NVS init with the standard ESP_ERR_NVS_NO_FREE_PAGES /
    NEW_VERSION_FOUND erase-and-retry recovery, StorageMount
    mount-or-format of /storage, and a one-line usage log (parity:
    storage usage in the serial status block, FR-008). Store
    instances are function-local statics constructed strictly after
    pumps_force_off() — the pumps-OFF-first invariant stays the first
    action in app_main — and wrapped in the Locked* decorators so
    every later consumer (console REPL task, controllers) goes
    through the mutex (FR-013). Storage failures are logged and
    non-fatal: config falls back to compiled-in defaults and the pump
    safety loop never depends on storage. E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
    [app_main.cpp]
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2026-06-13 feat(firmware): storage HIL console commands and wiring
    Define diag_console_register_storage() and register the config and
    storage commands in diag_console_start(), wiring the LockedConfigStore
    and LockedDataStorage instances from app_main into the REPL. Completes
    the HIL verification path for config persistence, factory reset and
    data storage on the rig.
    Task: T032
    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
    [app_main.cpp, diag_console.cpp]
2026-06-13 fix(storage): CP3 review — storeEvent stat-failure, stats/epoch test gaps, contract docs
    - F1: storeEvent no longer appends when stat() fails on an event file that
    holds valid bytes (would corrupt the frame boundary while returning true);
    an absent not-yet-created file still appends as before.
    - F2: add getStorageStats() provider-path test (no provider -> {0,0}; fake
    provider -> injected total/used).
    - F3: add non-monotonic-epoch chunk-bump test (sealed chunk + earlier-epoch
    append: no name collision, earlier record retrievable).
    - D1: document that NvsConfigStore.factoryReset() erases the entire default
    NVS partition, not just the wscfg namespace.
    - D2: note getEvents() newest-f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
    [IConfigStore.h]
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2026-07-02 feat(firmware): soil calibration tests, MockSoilSensor, console calibration commands
    T018-T027: FW-2/FW-4 confirmations (written in phase 3, verified),
    rev2 board build green with compile-time proof of no DE-pin reference,
    6 calibration host tests (factor computation, x100 register write,
    moisture-factor-not-applied parity, non-fatal write failure, validation
    on factored values), MockSoilSensor fixture for PR-11, soil_cal_*
    console commands, HIL checklist, firmware/CLAUDE.md sensors section,
    plan risk outcomes recorded (R5/R6 divergences documented, R2 open for
    HIL). Host suite 72/0.
    [diag_console.cpp]
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2026-07-02 fix(sensors): CP3 review fixes — calibration input hygiene, write-echo divergence, doc accuracy
    A1: reject non-finite/non-positive calibration references and factors
    exceeding the uint16 register encoding (UB before; NaN factors defeated
    range validation and poisoned readings as valid); console parse_float
    rejects non-finite input. A2+B1: 7 new host tests (untested validation
    branches temp>80/pH<3, boundary inclusivity, EC/NPK non-enforcement
    parity, calibration raw-read failure, invalid-reference and factor-
    overflow guards) + isAvailable lastError assert. A3: write-echo claim
    corrected — esp-modbus 2.1.2 validates FC06 framing only, no echoed-
    value comparison; documented as parity div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
    [EspModbusClient.cpp, app_main.cpp, diag_console.cpp]
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2026-07-02 feat(sensors): BME280 fault handling, address variants, Bosch vectors and docs
    US2-US4 + polish: host-testable sensor-task log policy
    (SensorTaskLogPolicy, bounded WARN cadence), MockEnvironmentalSensor with
    consistency helpers, 23 new host tests (error paths incl.
    calibration-re-read on module swap, 0x76/0x77 address matrix, negative-
    temperature and extreme-raw Bosch reference vectors, log policy, mock
    coherence) - suite 109/0. firmware/CLAUDE.md section, parity-checklist §6
    divergences, HIL checklist. Full verification: rev1+rev2 green from clean,
    dependencies.lock unchanged (T013-T025).
    [Bme280Sensor.cpp]
2026-07-02 fix(sensors): CP3 review — log visibility, error-code truth, mock UB, test hardening
    Review findings A1-A5, B1-B9, C1-C4+C8: infrastructure I2C failures now
    ESP_LOGE/WARN instead of compiled-out debug (wedged bus distinguishable
    from absent device); bounded init-failure logging (sensorless boot no
    longer WARNs every 5 s); NaN pre-first-read placeholders (self-announcing
    for non-gating consumers); MockEnvironmentalSensor initialize() reports
    error codes like the real driver; MockI2cBus wrap-around UB fixed;
    EspI2cBus handle table mutex-guarded for PR-05 multi-task sharing; env
    command concurrent-state hint; error-code docs corrected (mid-init error
    2, loss sequence 2-then-1); 10 new host te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
    [Bme280Sensor.cpp, EspI2cBus.cpp, diag_console.cpp]
2026-07-02 fix(sensors): correct v6 transaction NACK code in I2C log classification
    Re-review finding: i2c_master_transmit(_receive) return
    ESP_ERR_INVALID_RESPONSE on a device NACK in IDF v6 (ESP_ERR_NOT_FOUND is
    probe-only), so the expected-NACK debug branch in readRegisters/
    writeRegister was dead code and unplug NACKs logged at WARN. Classify
    ESP_ERR_INVALID_RESPONSE as expected-NACK; add HIL item C6 pinning the
    no-WARN-flood behavior on hardware (target-only path, not host-testable).
    [EspI2cBus.cpp]
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2026-07-03 feat(sensors): level sensors with debounce/settle gating and I2C 16-bit seam
    ILevelSensor/IPowerSensor/IDigitalInput interfaces; pure
    DebouncedLevelSensor (settle -> warm-up -> tracking state machine,
    300 ms stability window, board-owned polarity per FW-5, FW-3 settle
    gating via notifyPowerOn); GpioLevelSensor raw input (pull-ups, R4);
    LockedLevelSensor; level console command distinguishing not-yet-valid;
    board.h capability table incl. BOARD_HAS_RESERVOIR_PUMP (rev2 pin
    removed - rev2 target red until the T014 app_main gating lands next
    commit); II2cBus writeRegister16/readRegister16 extension through
    EspI2cBus and MockI2cBus. Host suite 139/0, rev1 green (T002-T013,
    T023 pulled forward).
    C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
    [EspI2cBus.cpp, GpioLevelSensor.cpp, app_main.cpp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]
2026-07-03 feat(sensors): reservoir-pump capability gating and INA226 power telemetry
    US2-US4 + polish: app_main/diag_console fully capability-gated
    (BOARD_HAS_RESERVOIR_PUMP - rev2 binary contains exactly one pump,
    compile-time enforced; force-off-first invariant capability-aware);
    Ina226Sensor pure driver (TI identity check, config 0x4527 derived from
    the datasheet field layout with TODO(PR-14) hardware confirmation,
    CAL=2048 @ 0.5 mA/5 mOhm from Kconfig WS_INA226_SHUNT_MILLIOHM,
    datasheet scaling incl. signed current) on the shared I2C bus with a
    16-bit word-register overlay in MockI2cBus; power/level console
    commands; MockLevelSensor with PR-11 truth-table consumer test;
    fail-direction truths pinne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
    [app_main.cpp, diag_console.cpp]
2026-07-03 fix(sensors): CP3 review — fault latch, invalid-state truth, test hardening
    Review findings F1-F15: level GPIO init failures now fault-latch the
    debounce state machine (isValid stays false until a deliberate
    notifyPowerOn re-arm - a floating unconfigured pin can no longer become
    a valid reading) with per-sensor init evaluation and logging (the ||
    short-circuit skipped the high-mark init entirely); isWaterPresent()
    returns false whenever invalid (was polarity-mapped construction
    default - phantom water-present on rev2 during settle; driver, interface
    doc and mock now agree); MockI2cBus aborts loudly on mismatched-shape
    reads of setRegister16-scripted words; stable textual anchors replace
    th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
    [GpioLevelSensor.cpp, app_main.cpp, board.h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]
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2026-07-04 feat(network): PR-07 US3 — config-button emergency provisioning + no-boot-loop
    Phase 5 / US3 + polish docs:
    - app_main: read BOARD_PIN_BTN_CONFIG (GPIO18, active-LOW/pull-up) at boot; held >=5s
    forces provisioning with 100ms status-LED blink; clears WiFi credentials first on an
    already-configured device (emergency reset). pumps_force_off() still first; hold loop
    bounded and only entered when pressed at boot.
    - WifiBootMode: pure shouldClearCredentialsOnBoot(credsPresent, buttonHeld)
    - host tests: no-boot-loop under permanent failure (800 rounds, bounded counters,
    never Connected/Provisioning), emergency-reset decision -> 176/0
    - firmware/CLAUDE.md: reference the FR9 SoftAP-portal d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
    [app_main.cpp]
2026-07-04 fix(network): PR-07 CP3 review fixes — reconnect/init robustness + diagnostics
    Addresses CP3 review findings (all verified, host 178/0, both boards green):
    - F1: WifiManager routes synchronous staConnect() failure through handleFailure
    so the reconnect cadence advances instead of wedging in Connecting forever
    - F4: handleFailure ignores stray failure events while ReconnectPaused (counter
    stays <= failuresBeforePause; 60s deadline not re-armed)
    - F3: EspWifiDriver::init() unwinds cleanly on event-handler registration failure
    (unregister handler, esp_wifi_deinit, delete queue) — no leak/dangling handler
    - F2: app_main gates provisioning AND station bring-up on WiFi-init success;
    wi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
    [app_main.cpp]
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2026-07-04 feat(events): PR-08 US2 — persistent event log (reset/wifi/pump) + boot reset reason
    Phase 4 / US2:
    - events component: EventLogger (pure, over IDataStorage + IWallClock) with typed
    producers (reset/wifi/pump start-stop/failsafe/ota), droppedEvents counter,
    resetReasonName mapping; reuses the PR-06 rotating event log (no interface change)
    - app_main: SystemWallClock + EventLogger; esp_reset_reason() -> logReset at boot
    - system_observer (main/): polls WifiManager snapshot + pump isRunning() from the
    10 Hz loop, logs WiFi state changes + pump start/stop; null-guarded
    - 6 host tests (EventLogger producers/failure/resetReasonName) vs MockDataStorage
    - TODO(US3/T018): construct SntpClien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
    [app_main.cpp]
2026-07-04 feat(watchdog): PR-08 US3 — esp_task_wdt on watering-critical tasks + SNTP wiring
    Phase 5 / US3 + polish:
    - task_watchdog helper: reconfigure to WS_TASK_WDT_TIMEOUT_S (20s, panic->reboot),
    subscribe/feed. Subscribes ONLY the 10 Hz main loop + the 5 s sensor task; the
    WiFi task and console REPL are deliberately NOT subscribed (a network stall must
    not reboot the device - FR-014). Idle-task WDT from sdkconfig retained.
    - SNTP wiring: app_main constructs SntpClient + applyTimezone(); SystemObserver
    starts SNTP once on the first WifiState::Connected; diag console 'time' registered.
    - boot order verified: pumps_force_off() first -> esp_reset_reason()->logReset ->
    watchdog_init() -> ta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
    [app_main.cpp]
2026-07-05 fix(008): CP3 review fixes (source) — event/watchdog/SNTP robustness
    Addresses CP3 findings F1-F6 + polish (host 187/0, both boards green):
    - F1: SystemObserver surfaces EventLogger droppedEvents() via ESP_LOGW (was a
    dead counter — a failing event store went silent)
    - F2: task watchdog preserves idle-task watching on all cores
    (idle_core_mask = (1<<portNUM_PROCESSORS)-1) + corrected comment
    - F3: EventLogger::logReset(int) maps reason internally (dropped the dead,
    mismatchable reasonName param)
    - F4: SyncStatus.synced() derived from lastSyncEpoch (no redundant bool);
    SntpClient::start() returns bool; observer retries SNTP if init failed
    - F5: resetReasonName extended to IDF v6 v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
    [app_main.cpp, diag_console.cpp]
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
